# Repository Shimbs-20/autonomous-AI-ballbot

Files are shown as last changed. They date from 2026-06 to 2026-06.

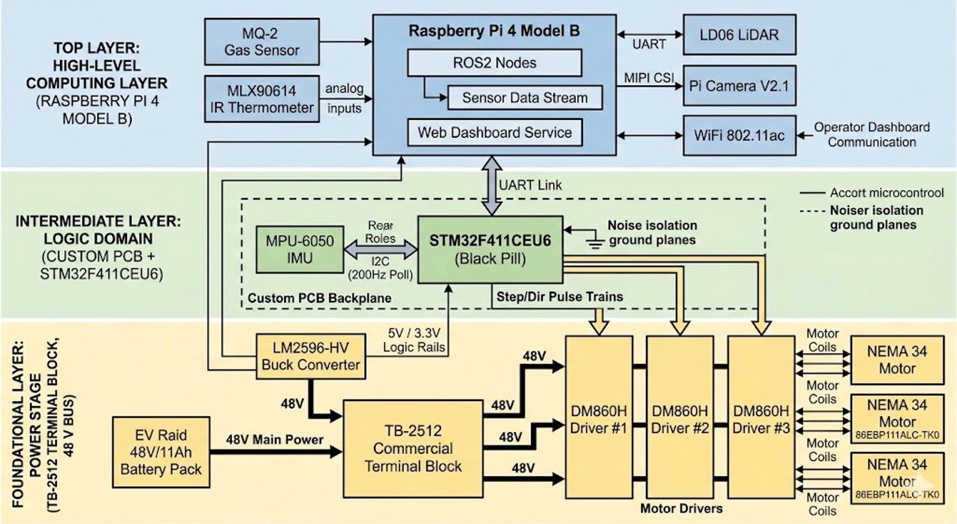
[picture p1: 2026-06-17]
docs/images/control architecture diagram.jpg

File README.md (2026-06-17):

# 🤖 Hazard Detection Ball Bot — Cairo University GP 2026

<div align="center">







**A self-balancing omnidirectional robot on a spherical wheel with real-time hazard detection, autonomous SLAM navigation, and a live web dashboard.**

*Cairo University · Faculty of Engineering · Mechatronics Graduation Project · Spring 2026*

</div>

---

## 📋 Table of Contents

- [Overview](#overview)
- [Demo](#demo)
- [Team](#team)
- [System Architecture](#system-architecture)
- [Hardware](#hardware)
- [Software Stack](#software-stack)
- [Repository Structure](#repository-structure)
- [Quick Start](#quick-start)
- [Control System](#control-system)
- [Navigation](#navigation)
- [Hazard Detection](#hazard-detection)
- [Web Dashboard](#web-dashboard)
- [Results](#results)
- [Bill of Materials](#bill-of-materials)
- [Acknowledgements](#acknowledgements)

---

## Overview

The Hazard Detection Ball Bot is an inverted-pendulum robot that balances on a single 350mm sphere driven by three omnidirectional wheels. It combines:

- **Real-time dynamic balancing** using a custom EKF (8-state) and LQI controller running at 200 Hz on STM32F411
- **Autonomous SLAM mapping** using a 360° LiDAR and slam_toolbox on Raspberry Pi 4
- **Hazard detection** using a custom-trained YOLOv8 NCNN model (fire, smoke, electrical hazard, person, obstacle) at 33+ FPS
- **Full ROS2 Navigation Stack** with MPPI holonomic controller for autonomous goal-seeking
- **Live web dashboard** accessible from any browser on the local network

The robot operates in four modes:
| Mode | Description |
|---|---|
| `0 STANDBY` | Motors off, safe state |
| `1 BALANCE` | Stationary self-balancing (LQI active) |
| `2 TELEOP` | Balance + velocity commands from Pi |
| `3 FLOOR DRIVE` | Direct omni-drive on casters (for SLAM mapping without balance risk) |

---

## Demo

> 📹 **[Demo Video — YouTube](#)** ← add link after recording

| SLAM Mapping | Hazard Detection | Dashboard |
|:---:|:---:|:---:|
| mapping | detection | dashboard |

---

## System Architecture

```
┌─────────────────────────────────────────────────────────────────────┐
│                        RASPBERRY PI 4B                              │
│                                                                     │
│  LD06 LiDAR ──→ /scan ──→ slam_toolbox ──→ /map                    │
│                              ↑                                      │
│  /odom ←── stm32_bridge ←── UART2 ←─────────────────────┐         │
│               │                                           │         │
│               └──→ twist_mux ──→ /cmd_vel ───────────────┘         │
│                      ↑              ↑                               │
│               PS4 joystick    Nav2 MPPI                             │
│                                                                     │
│  IMX219 ──→ /image_raw ──→ YOLOv8 NCNN ──→ /hazard_detections     │
│                                 └──→ /image_annotated               │
│                                                                     │
│  web_video_server (port 8080) + rosbridge (port 9090)               │
└──────────────────────────────┬──────────────────────────────────────┘
                               │ UART2 / 115200 baud
                               │ TX: 16-byte [AA][55][mode][vx][vy][yaw][XOR]
                               │ RX: 27-byte [BB][66][x][y][θ][vx][vy][yaw][XOR]
┌──────────────────────────────┴──────────────────────────────────────┐
│                    STM32F411 @ 96 MHz / FreeRTOS                    │
│                                                                     │
│  MPU6050 ──→ EKF (200 Hz, 8-state) ──→ LQI K[3×10]               │
│                        ↑                     ↓                      │
│  Encoders (TIM2/3/4) ──┘           convert_torque_to_speed          │
│                                             ↓                       │
│  TIM11 ISR (70021 Hz) ─── Bresenham ──→ 3× DM860H ──→ NEMA34      │
└─────────────────────────────────────────────────────────────────────┘
```

---

## Hardware

### Key Specifications

| Component | Specification |
|---|---|
| **Compute (embedded)** | STM32F411CEU6 @ 96 MHz, 128KB RAM |
| **Compute (high-level)** | Raspberry Pi 4B, 4GB RAM |
| **Motors** | 3× NEMA34 86BYGH127, 8.5 N·m holding torque |
| **Motor Drivers** | 3× DM860H, 48V / 7.2A, 16-microstep |
| **IMU** | MPU6050, ±16g / ±2000°/s, DLPF 44 Hz |
| **LiDAR** | LD06, 360°, 12m range, 230,400 baud |
| **Camera** | IMX219 (Pi Camera v2), 1080p, 30 FPS |
| **Ball** | 350mm diameter, rubber-tape coated, µ≈0.50 |
| **Battery** | 48V / 11Ah NMC (EV Raid) |
| **Total Height** | 925 mm |
| **Total Mass** | ~17 kg |

### Kinematic Geometry

```
Wheel placement:  γ₁=120°, γ₂=240°, γ₃=0° (equal spacing)
Zenith angle:     α = 45°
Ball radius:      Rk = 0.175 m
Wheel radius:     Rw = 0.0625 m
```

---

## Software Stack

```
Firmware (STM32):          ROS2 (Raspberry Pi):
  FreeRTOS                   ROS2 Humble / Jazzy
  STM32 HAL                  slam_toolbox (async SLAM)
  EKF (custom C)             Nav2 (MPPI Omni)
  LQI controller             AMCL localization
  USART2 DMA                 twist_mux
  Bresenham step engine      web_video_server
                             rosbridge_websocket
Vision:                    Dashboard:
  OpenCV                     HTML5 / JavaScript
  Ultralytics YOLOv8         ROSLIB.js
  NCNN inference             Web Video Server MJPEG
```

---

## Repository Structure

```
ballbot/
├── README.md
├── LICENSE
├── .gitignore
│
├── firmware/                   STM32CubeIDE project
│   ├── Core/
│   │   ├── Src/
│   │   │   ├── main.c          Main control loop (Modes 0-3)
│   │   │   ├── lqr.c           LQI controller + EKF interface
│   │   │   ├── Ekf.c           Extended Kalman Filter (8-state)
│   │   │   └── mpu6050.c       IMU driver
│   │   └── Inc/
│   │       ├── lqr.h
│   │       └── Ekf.h
│   └── README.md
│
├── ros2_ws/                    ROS2 workspace
│   └── src/
│       ├── ballbot_controller/ Bridge, teleop, mode control
│       ├── ballbot_mapping/    SLAM toolbox config + launch
│       ├── ballbot_navigation/ Nav2 params, behavior tree
│       ├── camera_pi/          Camera node + YOLOv8 detector
│       └── gp_description/     URDF + mesh files
│
├── matlab/                     Design and simulation
│   ├── system_model/           Nonlinear ball-bot dynamics
│   ├── lqi_design/             LQI gain matrix K[3×10] derivation
│   ├── ekf_design/             EKF Q/R tuning + verification
│   └── simulation/             Full closed-loop Simulink model
│
├── hardware/
│   ├── cad/                    SolidWorks assembly (.SLDASM, .STEP)
│   ├── pcb/                    Custom power board schematics
│   ├── BOM.md                  Complete bill of materials
│   └── README.md
│
└── dashboard/
    └── dashboard.html          Standalone web dashboard
```

---

## Quick Start

### Prerequisites

```bash
# On Raspberry Pi 4B — Bookworm 64-bit
sudo apt install -y ros-humble-desktop python3-colcon-common-extensions \
    ros-humble-slam-toolbox ros-humble-nav2-bringup \
    ros-humble-rosbridge-server ros-humble-web-video-server

pip install ultralytics opencv-python picamera2
```

### Build

```bash
cd ~/ros2_ws
colcon build --symlink-install
source install/setup.bash
```

### Run — Hardware bringup (Terminal 1)

```bash
# Testing without STM32
ros2 launch ballbot_controller pi_controller.launch.py

# Real robot — stationary balance
ros2 launch ballbot_controller pi_controller.launch.py \
    use_fake_odom:=false robot_mode:=1

# Real robot — SLAM mapping on floor (safest)
ros2 launch ballbot_controller pi_controller.launch.py \
    use_fake_odom:=false robot_mode:=3
```

### Run — SLAM mapping (Terminal 2)

```bash
ros2 launch ballbot_mapping slam.launch.py use_slam:=true

# Drive to map:
ros2 run teleop_twist_keyboard teleop_twist_keyboard

# Save when done:
ros2 run nav2_map_server map_saver_cli -f ~/maps/room
```

### Run — Autonomous navigation (Terminal 2)

```bash
ros2 launch ballbot_mapping slam.launch.py \
    use_slam:=false map_yaml:=~/maps/room.yaml

ros2 launch ballbot_navigation nav2.launch.py \
    use_slam:=false shelf_test:=false
# Then: RViz → 2D Pose Estimate → 2D Nav Goal
```

### Run — Camera + Hazard detection (Terminal 3)

```bash
ros2 launch camera_pi hazard.launch.py
# Dashboard: http://ballbot.local:8080
```

### Switch robot modes at runtime

```bash
ros2 topic pub --once /ballbot/mode std_msgs/msg/UInt8 '{data: 1}'  # BALANCE
ros2 topic pub --once /ballbot/mode std_msgs/msg/UInt8 '{data: 2}'  # TELEOP
ros2 topic pub --once /ballbot/mode std_msgs/msg/UInt8 '{data: 3}'  # FLOOR DRIVE
```

---

## Control System

### EKF — 8-State Observer

State vector: `[φ, θ, dφ, dθ, Vx, Vy, bias_x, bias_y]`

- **Sensor fusion**: MPU6050 gyro + accelerometer + 3 wheel encoders
- **Accelerometer spike rejection**: rejects readings outside [0.2g, 15g]
- **Motor-aware noise**: R_accel scales with motor speed (30→250)
- **Execution time**: ~0.4ms @96MHz (Joseph-form covariance update)

### LQI Controller — K[3×10]

```
Torque = −K × [φ, θ, ψ, Vx, Vy, dφ, dθ, ω_z, ∫Vx, ∫Vy]ᵀ
```

Gains tuned in MATLAB for: m=17kg, Rk=0.175m, Rw=0.0625m, α=45°, J_wheel=0.0032 kg·m²

### Inverse Kinematics (Mode 3 — Floor Drive)

Pseudo-inverse of forward kinematic matrix (verified: K·K⁺=I₂ₓ₂):

```
ω₁ = −1.617·vx − 0.933·vy + 1.980·ω_z
ω₂ = +1.617·vx − 0.933·vy + 1.980·ω_z
ω₃ = +0.000·vx + 1.867·vy + 1.980·ω_z
```

---

## Navigation

- **SLAM**: slam_toolbox async_online, 5cm/cell, Ceres solver
- **Localization**: AMCL with OmniMotionModel
- **Planner**: SmacPlanner2D (A*, holonomic — no heading constraint)
- **Controller**: MPPI, 300 trajectories, `motion_model: Omni`, vy_max=0.5 m/s
- **Behavior tree**: ClearCostmap → Spin → BackUp → Wait
- **Velocity arbitration**: twist_mux — PS4(100) > keyboard(50) > Nav2(10)

---

## Hazard Detection

| Class | mAP@0.5 | Triggers E-Stop |
|---|---|---|
| 🔥 Fire | 94.2% | ✅ |
| 💨 Smoke | 91.8% | ✅ |
| ⚡ Electrical Hazard | 88.7% | ✅ |
| 👤 Person | 96.5% | ❌ |
| 🚧 Obstacle | 85.3% | ❌ |

- **Model**: YOLOv8n converted to NCNN for Pi 4 CPU inference
- **Input**: 416×416 letterbox (aspect-ratio preserving)
- **Output**: 640×480 annotated MJPEG to web dashboard
- **Throughput**: 33.4 FPS average on Raspberry Pi 4B

---

## Web Dashboard

Accessible at `http://ballbot.local:8080` or `http://<Pi-IP>:8080`

**Features:**
- Live MJPEG camera feed (annotated with bounding boxes)
- Real-time SLAM map rendering from `/map` OccupancyGrid
- LiDAR scan overlay on map
- Odometry trail
- Mode control buttons (0/1/2/3) via `/ballbot/mode`
- Hazard detection cards with proximity indicator
- CPU temperature gauge
- Emergency stop overlay

**Dependencies:** rosbridge_websocket (port 9090), web_video_server (port 8080)

---

## Results

| Metric | Value |
|---|---|
| Control loop frequency | 200 Hz |
| EKF execution time | ~0.4 ms |
| Stepper ISR frequency | 70,021 Hz |
| SLAM map resolution | 5 cm/cell |
| Nav2 goal success rate | 100% (lab trials) |
| Detection FPS | 33.4 FPS |
| Detection classes | 5 |
| Total system mass | 17 kg |
| Battery endurance | ~2 hours |

---

## Bill of Materials

See [`hardware/BOM.md`](hardware/BOM.md) for the complete list.

**Major components:**

| Item | Qty | Est. Cost |
|---|-----|---|
| STM32F411 Black Pill | 1 | $5 |
| Raspberry Pi 4B 4GB | 1 | $55 |
| NEMA34 stepper 86BYGH127 | 3 | $45 each |
| DM860H stepper driver | 3 | $30 each |
| MPU6050 IMU module | 1 | $3 |
| LD06 LiDAR | 1 | $90 |
| Pi Camera Module v2 (IMX219) | 1 | $25 |
| 48V 11Ah NMC battery pack | 1 | $120 |
| Omni roller ball 350mm | 1 | $80 |
| **Total (approx.)** | | **~$1,480** |

---

## Acknowledgements

This project was completed as the Graduation Project 2 (GP2) for the Mechatronics program at Cairo University Faculty of Engineering, Spring 2026.

We thank Dr. Hossam H. Ammar and Dr. Moataz El-Sisi for their guidance throughout the project.

**References:**
- Lauwers, T. B. et al., "A Dynamically Stable Single-Wheeled Mobile Robot with Inverse Mouse-Ball Drive" — ICRA 2006
- Geyer, H., "Ballbot: The Fast, Omnidirectional Balancing Mobile Robot" — CMU 2010
- Welch, G. and Bishop, G., "An Introduction to the Kalman Filter" — UNC 1995

---

<div align="center">
Cairo University · Faculty of Engineering · Spring 2026
</div>

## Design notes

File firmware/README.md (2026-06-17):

# STM32 Firmware

**Platform**: STM32F411CEU6 (Black Pill) @ 96 MHz  
**RTOS**: FreeRTOS (CMSIS-RTOS v1)  
**IDE**: STM32CubeIDE 1.14+

---

## File Map

| File | Purpose |
|---|---|
| `Core/Src/main.c` | Hardware init, all 4 robot modes, stepper ISR |
| `Core/Src/lqr.c` | LQI gain matrix, EKF interface, watchdog |
| `Core/Inc/lqr.h` | Public API: `controlLoop()`, `setControlMode()`, extern state vars |
| `Core/Src/Ekf.c` | 8-state EKF (predict + Joseph-form update) |
| `Core/Src/mpu6050.c` | MPU6050 I2C driver (400 kHz) |

---

## Robot Modes

| Mode | Value | Description |
|---|---|---|
| `STANDBY` | 0 | Motors off, EKF reset |
| `BALANCE` | 1 | LQI active, velocity refs = 0 |
| `TELEOP` | 2 | LQI + velocity commands from Pi, binary odom @ 20 Hz |
| `FLOOR_DRIVE` | 3 | Direct inverse kinematics, no balance, binary odom @ 20 Hz |

---

## UART Protocol

**Pi → STM32** (16 bytes, 50 Hz):
```
[0xAA][0x55][mode:u8][vx:f32 LE][vy:f32 LE][yaw:f32 LE][XOR of bytes 2-14]
```

**STM32 → Pi** (27 bytes, 20 Hz — Modes 2 & 3 only):
```
[0xBB][0x66][x:f32][y:f32][θ:f32][vx:f32][vy:f32][yaw:f32][XOR of bytes 2-25]
```

---

## Key Parameters to Tune

```c
// lqr.c
const float LPF_ALPHA   = 0.5f;   // Torque LPF — higher = faster response
const float MAX_INTEGRAL = 0.3f;  // Anti-windup on velocity integral

// main.c
#define TORQUE_TO_OMEGA   5.0f    // (rad/s)/Nm — increase if response is slow
#define MAX_RAMP          500     // Steps/loop — increase for faster acceleration
#define PHI_OFFSET       -0.022f  // Calibrate to your robot's mounting angle
#define THETA_OFFSET     -0.185f  // Calibrate to your robot's mounting angle
```

---

## Flashing

1. Open project in STM32CubeIDE
2. Connect ST-Link to SWD header (SWDIO, SWCLK, GND, 3.3V)
3. **Run → Debug** (first flash) or **Run → Run** (subsequent)

> ⚠️ Keep robot still for 2 seconds after power-on — gyro bias calibration runs automatically.

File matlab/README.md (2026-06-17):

# MATLAB Design Files

All system modeling, controller design, and EKF tuning was done in MATLAB R2023b.

---

## Folder Structure

```
matlab/
├── system_model/         Nonlinear ball-bot equations of motion
│   ├── ballbot_eom.m     Derives the Lagrangian EOM symbolically
│   └── linearize.m       Linearizes about upright equilibrium
│
├── lqi_design/           LQI gain matrix K[3×10]
│   ├── lqi_design.m      Main script — sets Q, R, solves DARE
│   ├── verify_poles.m    Checks closed-loop poles
│   └── K_LQI.mat         Saved gain matrix used in firmware
│
├── ekf_design/           EKF noise matrix tuning
│   ├── ekf_tuning.m      Sweeps Q, R parameters
│   └── verify_ekf.m      Monte Carlo verification
│
└── simulation/           Full closed-loop simulation
    ├── ballbot_sim.slx   Simulink model (nonlinear plant + LQI)
    └── plot_results.m    Generates response plots
```

---

## LQI State Vector

```
x = [φ, θ, ψ, Vx, Vy, dφ, dθ, ω_z, ∫Vx, ∫Vy]ᵀ
```

| Index | State | Unit |
|---|---|---|
| 0 | φ (roll tilt) | rad |
| 1 | θ (pitch tilt) | rad |
| 2 | ψ (yaw) | rad |
| 3 | Vx (ball velocity) | m/s |
| 4 | Vy (ball velocity) | m/s |
| 5 | dφ (roll rate) | rad/s |
| 6 | dθ (pitch rate) | rad/s |
| 7 | ω_z (yaw rate) | rad/s |
| 8 | ∫Vx | m |
| 9 | ∫Vy | m |

---

## Physical Parameters Used

```matlab
m_body = 15.0;   % robot body mass [kg]
m_ball = 2.0;    % ball mass [kg]
Rk     = 0.175;  % ball radius [m]
Rw     = 0.0625; % wheel radius [m]
alpha  = pi/4;   % zenith angle [rad]
J_body = 1.2;    % body inertia [kg·m²]
J_wheel = 0.0032;% wheel inertia [kg·m²]
g      = 9.81;   % gravity [m/s²]
```

---

## Running the Design

```matlab
% 1. Derive linearized model
cd system_model
run('linearize.m')   % outputs A, B matrices

% 2. Design LQI gains
cd ../lqi_design
run('lqi_design.m')  % outputs K_LQI [3×10]

% 3. Verify with full simulation
cd ../simulation
open('ballbot_sim.slx')
sim('ballbot_sim')
run('../simulation/plot_results.m')
```

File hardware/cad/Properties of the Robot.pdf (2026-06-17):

Mass properties of BallBot Configuration: Default
Coordinate system: -- default --

Mass = 17273.33 grams

Volume = 8145880.07 cubic millimeters

Surface area = 178916.26 square millimeters

Center of mass: ( millimeters )
X = 137.84
Y = 1403.20
Z = 1346.20

Principal axes of inertia and principal moments of inertia: ( grams * square millimeters ) aTken at the center of mass.
Ix = ( 0.07, -0.13, 0.99) | Px = 163549822.66
Iy = (-0.12, -0.99, -0.12) | Py = 645272933.77
Iz = ( 0.99, -0.1, -0.08) | Pz = 663321789.23

Moments of inertia: ( grams * square millimeters )
aTken at the center of mass and aligned with the output coordinate system. Lxx = 660683706.39 Lxy = -2439602.08 Lxz = 34361266.06

Lyx = -2439602.08 Lyy = 637029246.26 Lyz = -63295347.25 Lzx = 34361266.06 Lzy = -63295347.25 Lzz = 174431593.00

Moments of inertia: ( grams * square millimeters ) aTken at the output coordinate system.
Ixx = 65974821416.04 | Ixy = 3338489453.96Ixz = 3239566099.79
Iyx = 3338489453.96Iyy = 32268675137.18 | Iyz = 32565708478.27
Izx = 3239566099.79Izy = 32565708478.27 | Izz = 34513294168.06

One or more components have overridden mass properties: single Roda Omni 100 mm<1><Default>@Lower part assembly<1><Default> single Roda Omni 100 mm<2><Default>@Lower part assembly<1><Default> single Roda Omni 100 mm<3><Default>@Lower part assembly<1><Default> CS-D508<1><Default>@Lower part assembly<1><Default> CS-D508<2><Default>@Lower part assembly<1><Default> CS-D508<3><Default>@Lower part assembly<1><Default> Nema34<1><Default>@Lower part assembly<1><Default> Nema34<2><Default>@Lower part assembly<1><Default> Nema34<3><Default>@Lower part assembly<1><Default> LD06_Assembly<1><Default>@Upper layer<1><Default> final_assembly<1><Default>@Upper layer<1><Default> MLX90614XAA_Module<2><Default>
EV raid battery<1><Default>

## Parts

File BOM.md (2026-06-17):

# Bill of Materials — Hazard Detection Ball Bot

*Cairo University GP 2026 · Total estimated cost: ~$1,480 USD*

---

## Compute & Electronics

| # | Component | Specification | Qty | Unit Cost | Total |
|---|---|---|-----|---|---|
| 1 | **Raspberry Pi 4B** | 4GB RAM, 64-bit | 1 | $55 | $55 |
| 2 | **STM32F411 Black Pill** | 96 MHz, 128KB RAM, USB-C | 1 | $5 | $5 |
| 3 | **MPU6050 IMU** | ±16g / ±2000°/s, I2C | 1 | $3 | $3 |
| 4 | **LD06 LiDAR** | 360°, 12m, 10Hz, UART | 1 | $90 | $90 |
| 5 | **Pi Camera Module v2** | IMX219, 8MP, CSI | 1 | $25 | $25 |
| 6 | **MicroSD Card** | 64GB, Class 10, A2 | 1 | $12 | $12 |

---

## Actuators & Drivers

| # | Component | Specification | Qty | Unit Cost | Total |
|---|---|---|-----|---|---|
| 7 | **NEMA34 Stepper** | 86BYGH127, 8.5 N·m | 3 | $45 | $135 |
| 8 | **DM860H Driver** | 48V, 7.2A, 16-microstep | 3 | $30 | $90 |
| 9 | **Coupling (D25L30)** | 6mm to 8mm, rigid | 3 | $4 | $12 |

---

## Power

| # | Component | Specification | Qty | Unit Cost | Total |
|---|---|---|-----|---|---|
| 10 | **48V NMC Battery** | 11Ah, EV Raid | 1 | $120 | $120 |
| 11 | **DC-DC Converter** | 48V→5V/5A (Pi + sensors) | 1 | $15 | $15 |
| 12 | **DC-DC Converter** | 48V→12V/3A (aux) | 1 | $12 | $12 |
| 13 | **E-Stop Switch** | 40A, key-lock, NC | 1 | $18 | $18 |
| 14 | **Power Fuse** | 30A blade fuse + holder | 2 | $3 | $6 |
| 15 | **XT60 Connectors** | Male + Female pair | 4 | $2 | $8 |

---

## Mechanical

| # | Component | Specification | Qty | Unit Cost | Total |
|---|---|---|-----|---|---|
| 16 | **Omnidirectional Ball** | 350mm, polyurethane | 1 | $80 | $80 |
| 17 | **Omnidirectional Wheel** | 125mm Mecanum/omni | 3 | $35 | $105 |
| 18 | **Aluminum Profile** | 40×40mm, various lengths | ~4m | $8/m | $32 |
| 19 | **Aluminum Plates** | 6mm, laser-cut | 3 | $20 | $60 |
| 20 | **Ball Caster Wheels** | 50mm, steel ball | 3 | $8 | $24 |
| 21 | **Bearings** | 6200-2RS, 10×30×9 | 6 | $3 | $18 |
| 22 | **M3/M4/M5 Hardware** | Bolts, nuts, standoffs | set | $15 | $15 |
| 23 | **Rubber Tape** | 50mm wide, grip coating | 1 roll | $8 | $8 |

---

## Wiring & PCB

| # | Component | Specification | Qty | Unit Cost | Total |
|---|---|---|-----|---|---|
| 24 | **Custom PCB** | Power distribution + logic | 1 | $45 | $45 |
| 25 | **Wiring Harness** | 18AWG + 22AWG silicone | set | $20 | $20 |
| 26 | **AM26LS32 Receiver** | Differential RS-422 encoder | 3 | $2 | $6 |
| 27 | **JST Connectors** | XH2.54, PH2.0 assortment | set | $10 | $10 |
| 28 | **Ferrite Beads** | 100MHz, signal lines | 10 | $0.50 | $5 |

---

## Summary

| Category | Cost |
|---|---|
| Compute & Electronics | $190 |
| Actuators & Drivers | $237 |
| Power | $179 |
| Mechanical | $342 |
| Wiring & PCB | $86 |
| **Total** | **~$1,034** |
| + Shipping / Contingency (30%) | ~$310 |
| **Grand Total** | **~$1,344** |

> Prices are approximate as of early 2026. Actual project budget: **~$1,480 USD**.

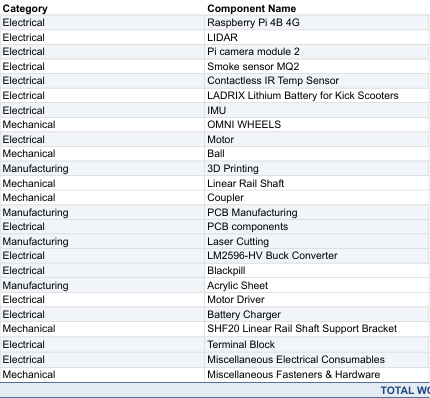
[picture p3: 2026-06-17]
docs/images/BOM1.png

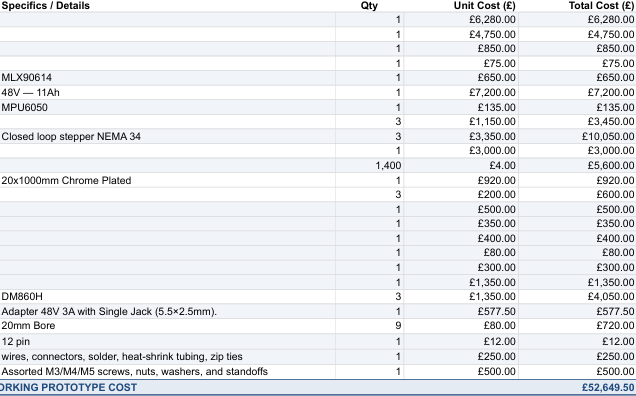
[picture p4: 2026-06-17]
docs/images/BOM2.png

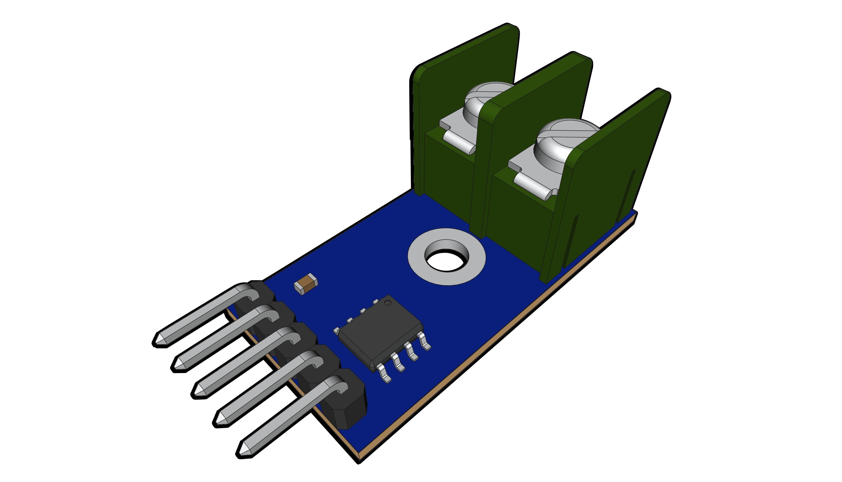
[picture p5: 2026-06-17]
hardware/cad/Parts/Electrical Parts/max6675-spi-thermocouple-amplifier-and-thermocouple-1.snapshot.11/Iso 01.png

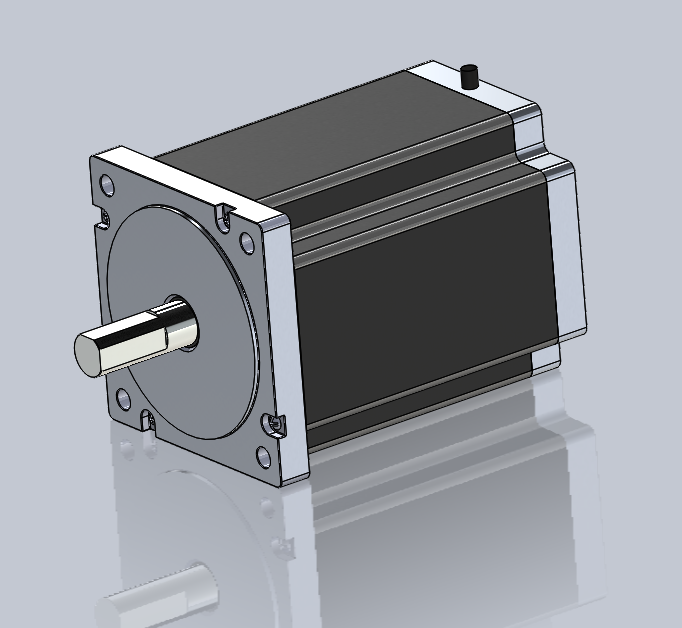
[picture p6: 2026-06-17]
hardware/cad/Parts/Electrical Parts/nema-34-stepper-motor-7.snapshot.7/Nema34-1.PNG

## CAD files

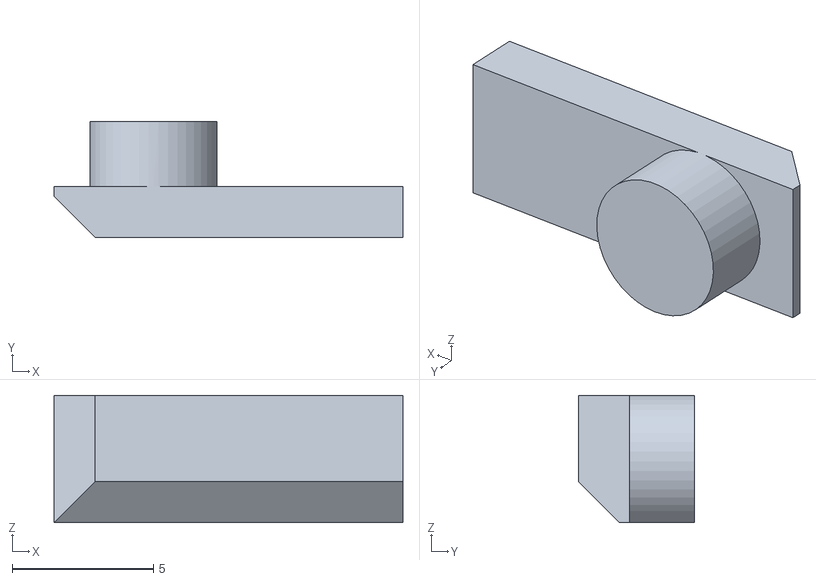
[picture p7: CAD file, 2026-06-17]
hardware/cad/Parts/3d printed/RaspberryCaseSTL/final_assembly - Copy - Rubber pads - Copy-1.STL
12.3 x 4.10 x 4.50

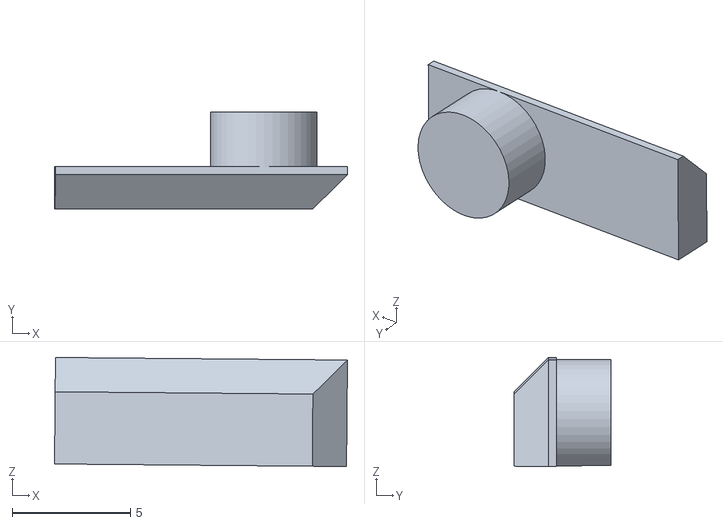
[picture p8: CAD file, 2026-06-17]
hardware/cad/Parts/Mechanical parts/raspberry-pi-4-case-4.snapshot.4/RaspberryCaseSTL/final_assembly - Copy - Rubber pads - Copy-2.STL
12.4 x 4.10 x 4.61

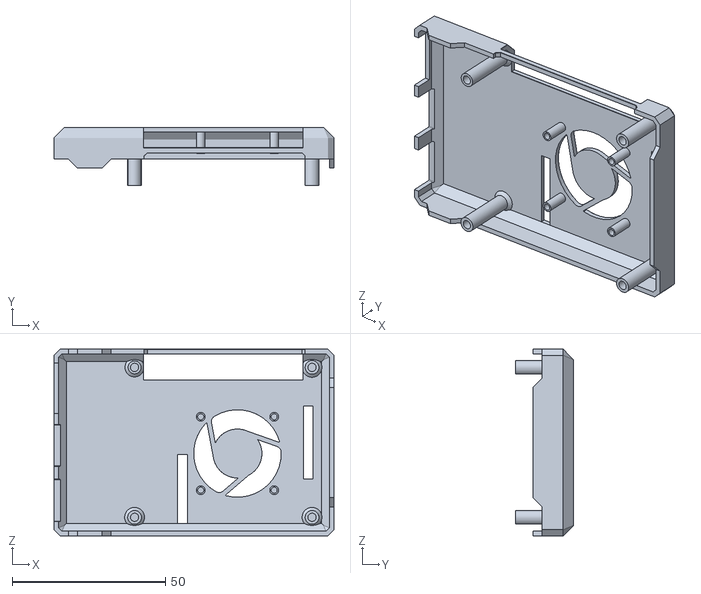
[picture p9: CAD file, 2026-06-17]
hardware/cad/Parts/Mechanical parts/raspberry-pi-4-case-4.snapshot.4/RaspberryCaseSTL/final_assembly - Copy - TOP-1.STL
91.5 x 19.0 x 61.0

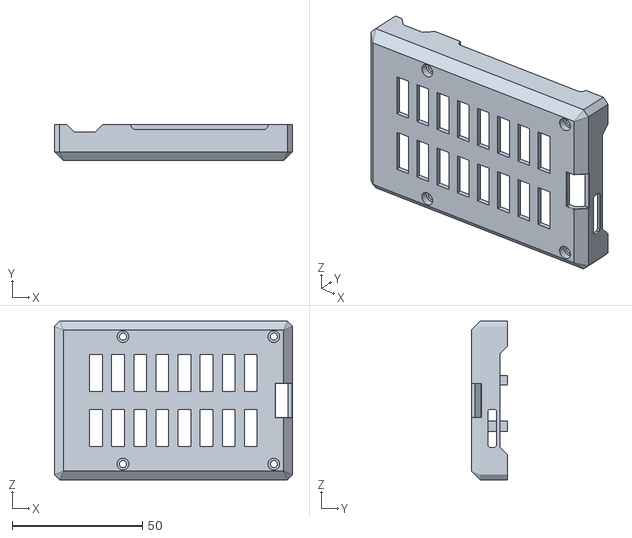
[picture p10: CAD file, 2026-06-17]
hardware/cad/Parts/Mechanical parts/raspberry-pi-4-case-4.snapshot.4/RaspberryCaseSTL/final_assembly - Copy - base-2.STL
91.5 x 14.0 x 61.0

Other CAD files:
hardware/cad/Assemblies/PCBs.SLDASM
hardware/cad/Parts/Mechanical parts/raspberry-pi-4-case-4.snapshot.4/RaspberryPi Thermal Cooling/final_assembly.SLDASM
hardware/cad/The assembly/BallBot.SLDASM
hardware/cad/Assemblies/Upper layer.SLDASM
hardware/cad/Assemblies/PCB and Controllers layer.SLDASM
hardware/cad/Parts/3d printed/RaspberryCaseSTL/final_assembly - Copy - Rubber pads-1.STL
hardware/cad/Parts/Mechanical parts/raspberry-pi-4-case-4.snapshot.4/RaspberryCaseSTL/final_assembly - Copy - Rubber pads-5.STL
hardware/cad/Assemblies/Electronics layer (Batterys layer).SLDASM
hardware/cad/Assemblies/Lower part assembly.SLDASM
hardware/cad/Parts/3d printed/RaspberryCaseSTL/final_assembly - Copy - Rubber pads-5.STL
hardware/cad/Parts/Electrical Parts/ldrobot-ld06-360-lidar-module-raspberry-pi-mounting-bracket-1.snapshot.4/LD06_Assembly.STEP
hardware/cad/Assemblies/Base layer.SLDPRT
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

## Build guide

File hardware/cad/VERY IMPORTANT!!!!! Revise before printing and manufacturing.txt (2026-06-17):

1. Motor mounting holes placement
2. Motor Omni Wheel coupling
3. Use https://fluxelectronix.com/shop/m5-knurled-brass-threaded-insert-nut/ for screw holes for 3d prints
4. Driver mounting holes
5. Rod length
6. check ball contact with Omni wheels
7. Rod support holes

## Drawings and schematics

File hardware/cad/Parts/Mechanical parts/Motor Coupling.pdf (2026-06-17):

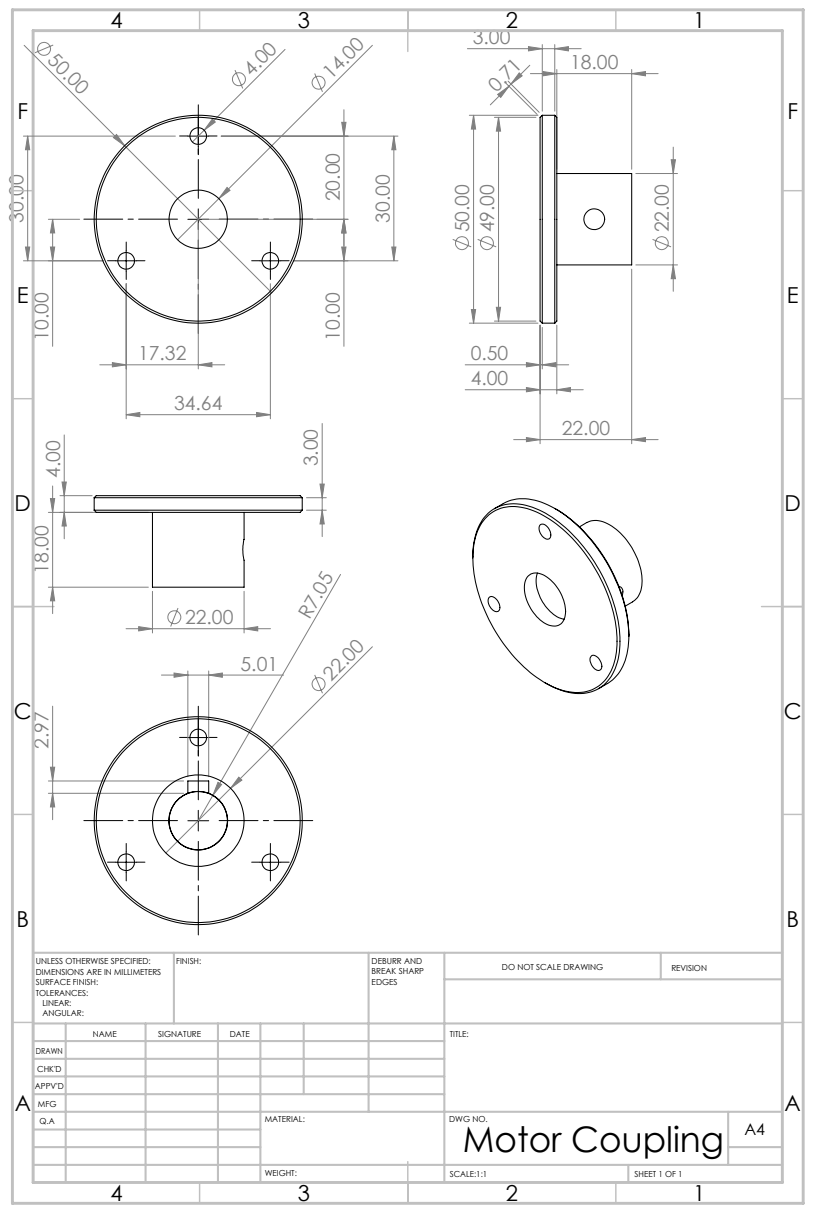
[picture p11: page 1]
FINISH:; DEBURR AND; BREAK SHARP; DO NOT SCALE DRAWING; REVISION; SCALE:1:1; SHEET 1 OF 1

UNLESS OTHERWISE SPECIFIED:
DIMENSIONS ARE IN MILLIMETERS
SURFACE FINISH:
TOLERANCES:
LINEAR:
ANGULAR:

NAME | SIGNATURE | DATE | | | | TITLE:

DRAWN
CHK'D
APPV'D
MFG
Q.A | | | | MATERIAL: | DWG NO. Motor Coupling | A4

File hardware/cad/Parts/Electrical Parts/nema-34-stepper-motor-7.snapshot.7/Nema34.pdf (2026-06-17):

6
8.20

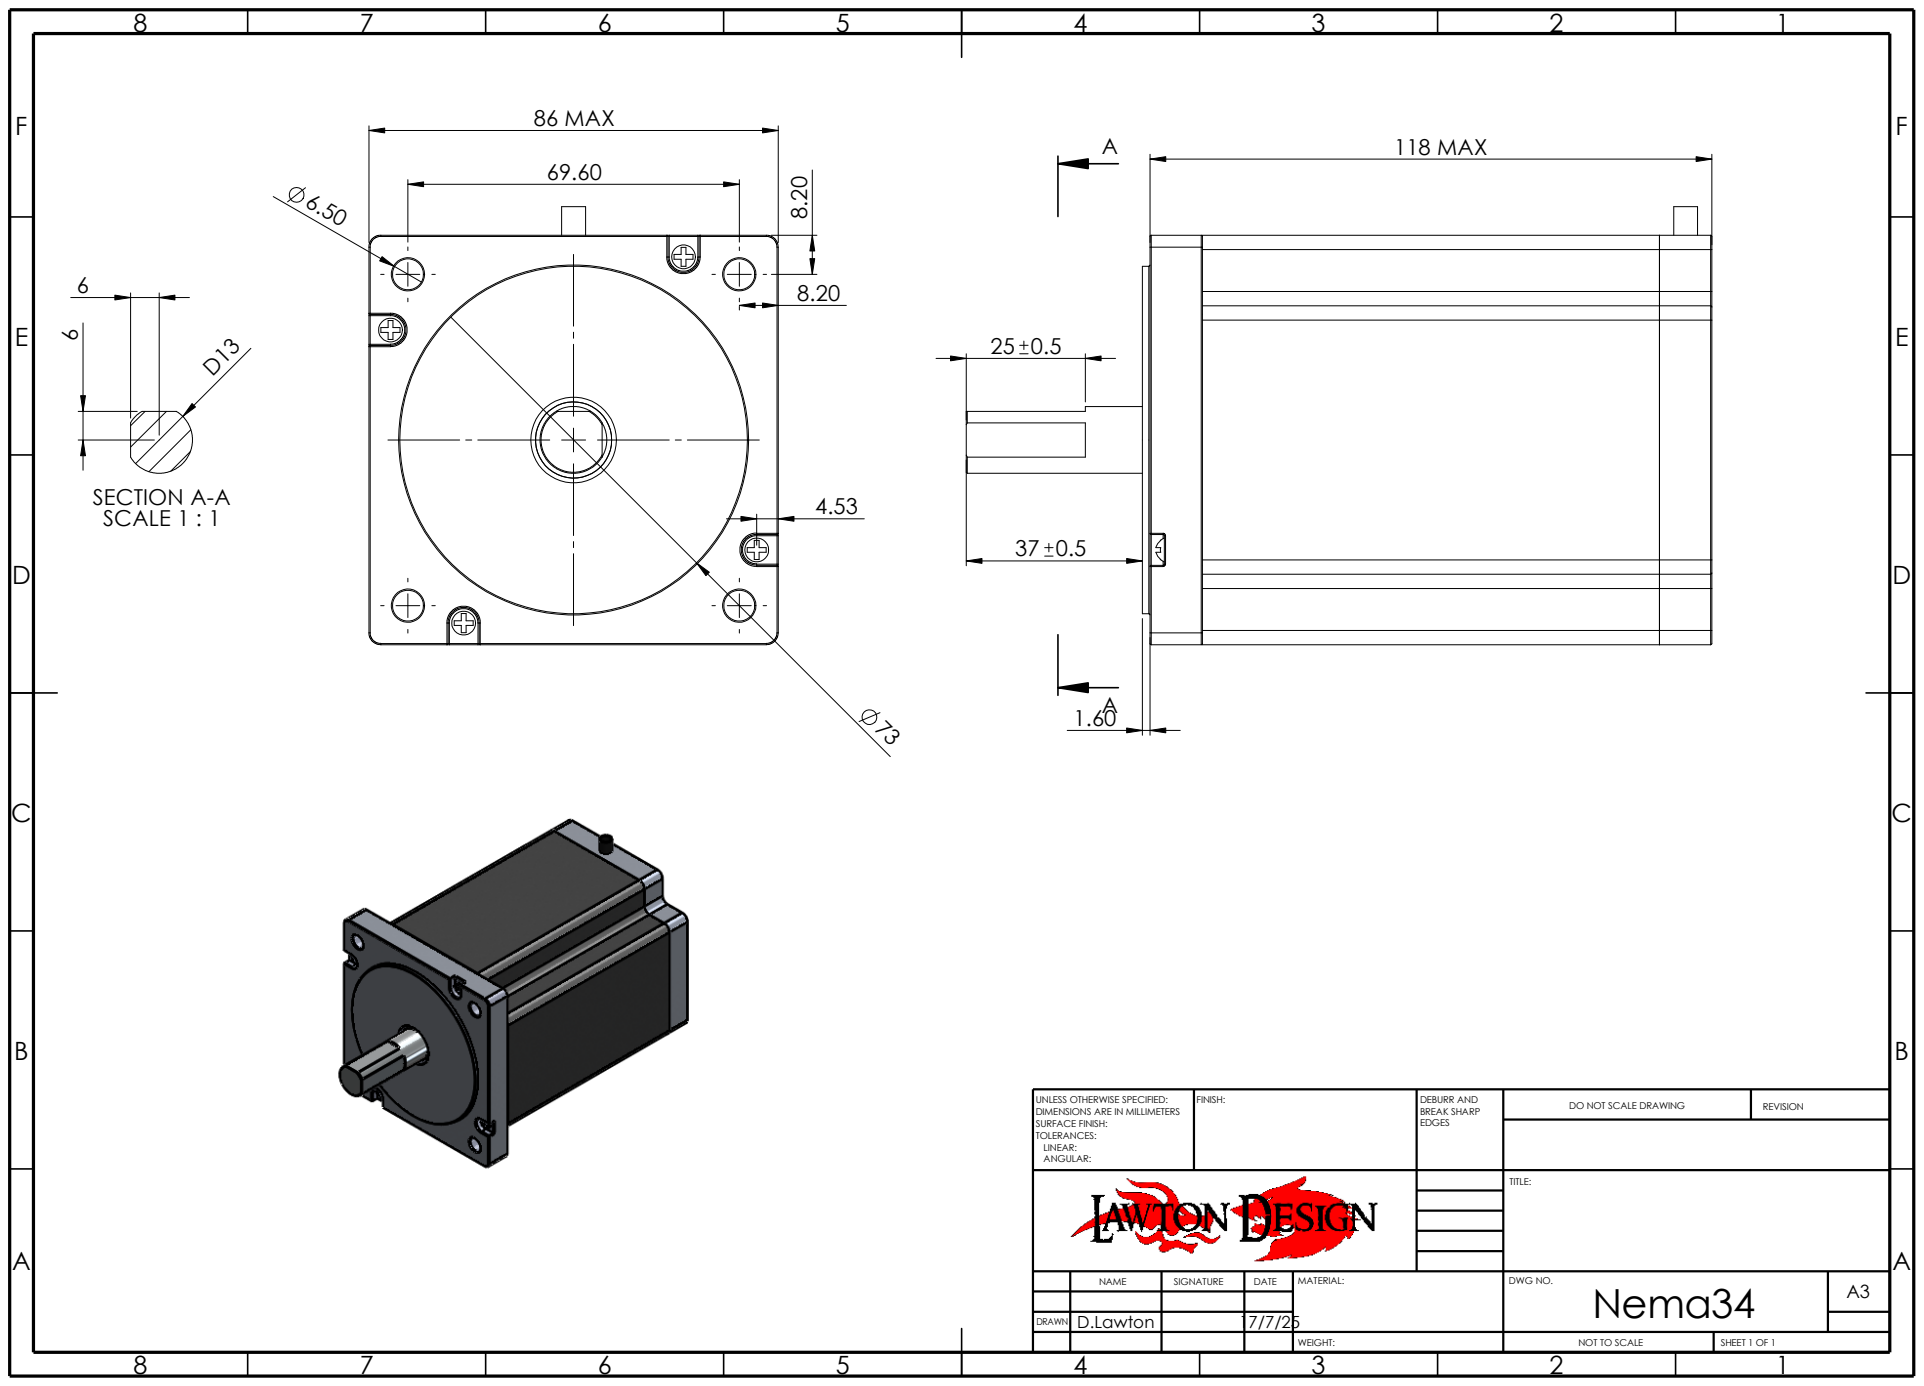
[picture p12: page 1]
SECTION A-A SCALE 1 : 1; 86 MAX; 118 MAX; DO NOT SCALE DRAWING; REVISION; FINISH:; EDGES; DEBURR AND; BREAK SHARP

UNLESS OTHERWISE SPECIFIED:
DIMENSIONS ARE IN MILLIMETERS
SURFACE FINISH:
TOLERANCES:
LINEAR:
ANGULAR:

TITLE:

NAME | SIGNATURE | DATE | MATERIAL: | DWG NO. Nema34 | A3

DRAWN | D.Lawton | 17/7/25

WEIGHT: | NOT TO SCALE | SHEET 1 OF 1

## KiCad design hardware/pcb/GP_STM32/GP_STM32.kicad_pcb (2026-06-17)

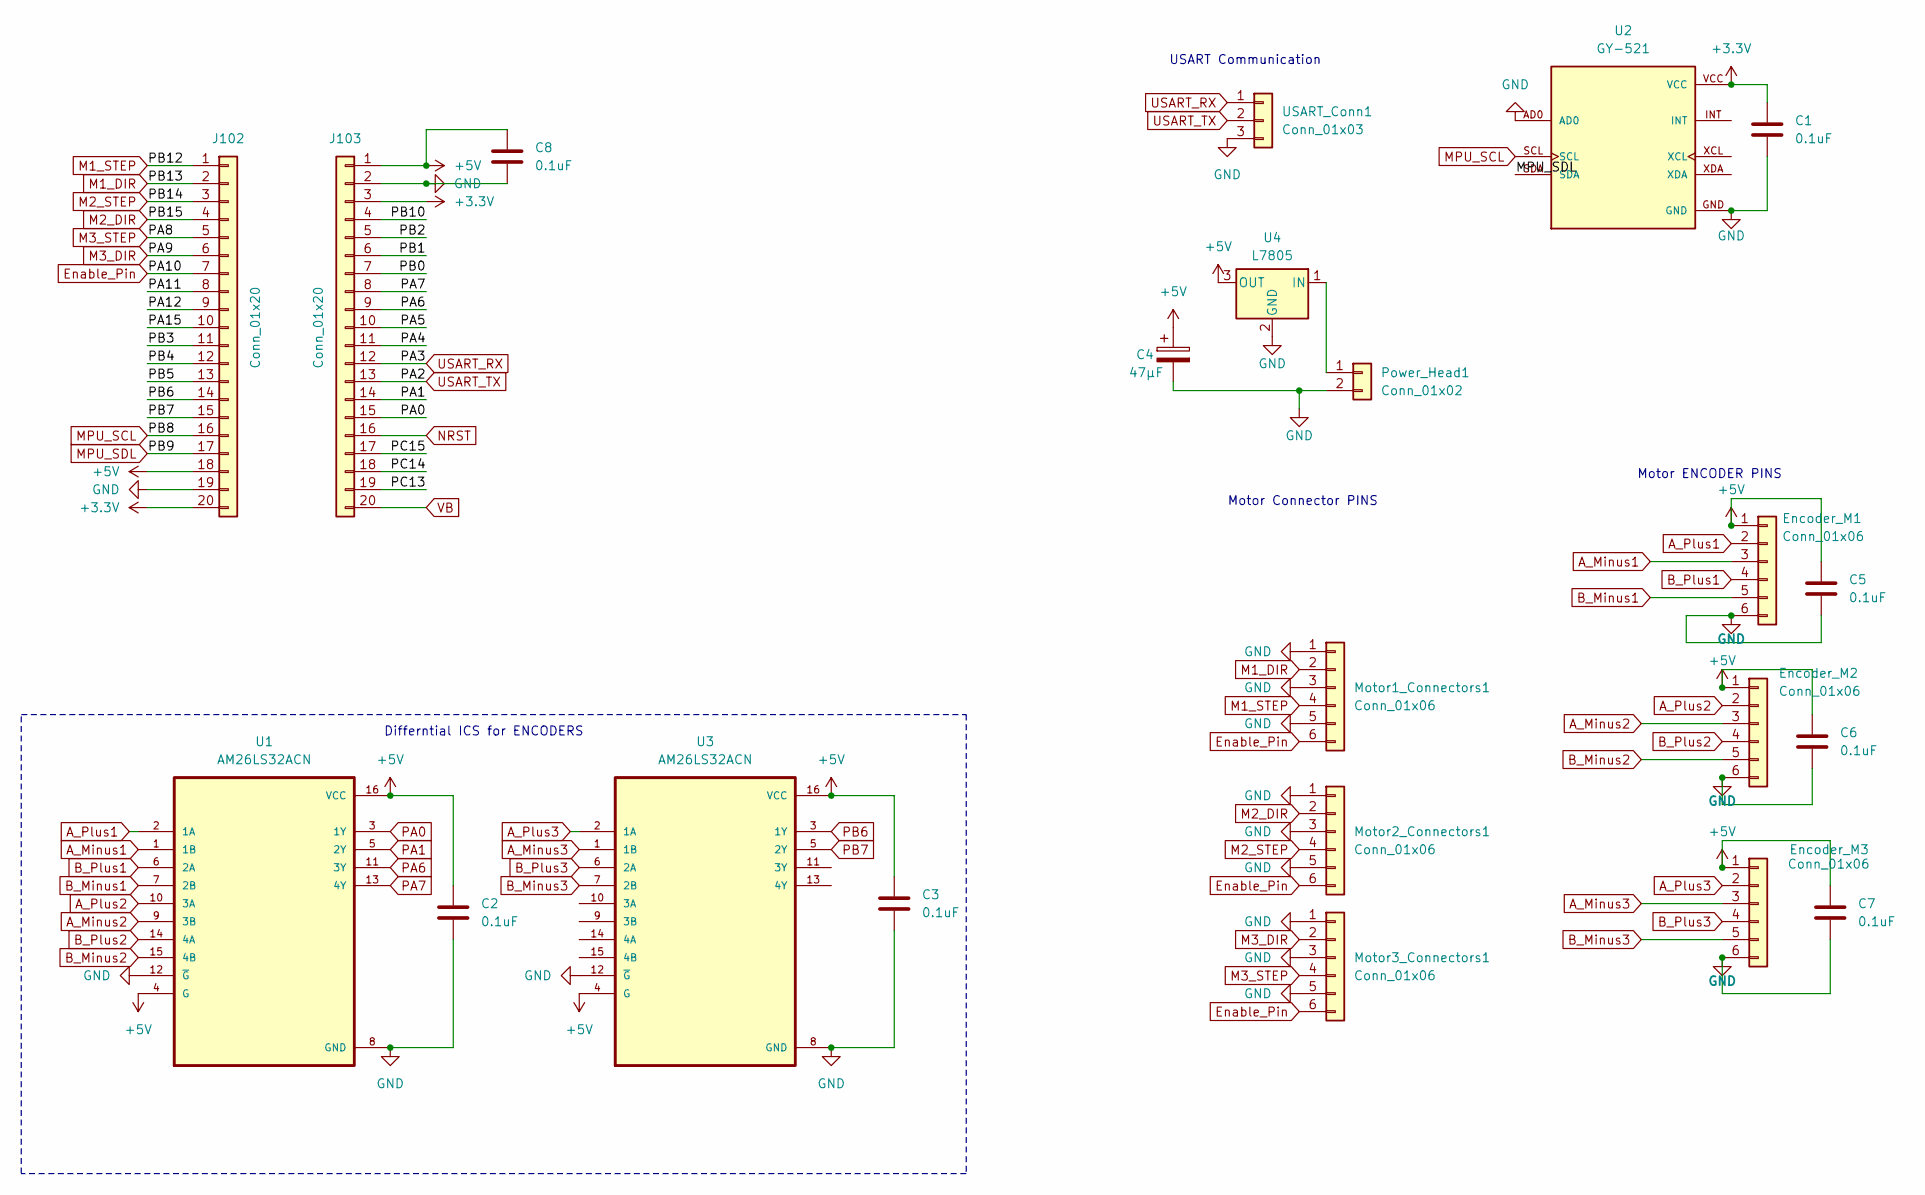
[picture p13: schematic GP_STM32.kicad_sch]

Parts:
C1, C2, C3, C5, C6, C7, C8: 0.1uF; C_Disc_D5.0mm_W2.5mm_P5.00mm
C4: 47µF; CP_Radial_D6.3mm_P2.50mm
Encoder_M1, Encoder_M2, Encoder_M3: Conn_01x06; JST_XH_B6B-XH-A_1x06_P2.50mm_Vertical
J102, J103: Conn_01x20; PinHeader_1x20_P2.54mm_Vertical
Motor1_Connectors1, Motor2_Connectors1, Motor3_Connectors1: Conn_01x06; JST_XH_B6B-XH-A_1x06_P2.50mm_Vertical
Power_Head1: Conn_01x02; TerminalBlock_MaiXu_MX126-5.0-02P_1x02_P5.00mm
U1, U3: AM26LS32ACN; DIP-16_W7.62mm
U2: GY-521; MODULE_GY-521; PARTREV NA
U4: L7805; TO-220-3_Vertical
USART_Conn1: Conn_01x03; JST_XH_B3B-XH-A_1x03_P2.50mm_Vertical

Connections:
+3.3V: C1.1, J102.20, J103.3, U2.VCC
+5V: C2.1, C3.1, C4.1, C5.1, C6.1, C7.1, C8.1, Encoder_M1.1, Encoder_M2.1, Encoder_M3.1, J102.18, J103.1, U1.4 (G), U1.16 (VCC), U3.4 (G), U3.16 (VCC), U4.3 (OUT)
/PA4: J103.11
/PA5: J103.10
/PA11: J102.8
/PA12: J102.9
/PA15: J102.10
/PB0: J103.7
/PB1: J103.6
/PB2: J103.5
/PB3: J102.11
/PB4: J102.12
/PB5: J102.13
/PB10: J103.4
/PC13: J103.19
/PC14: J103.18
/PC15: J103.17
A_Minus1: Encoder_M1.3, U1.1 (1B)
A_Minus2: Encoder_M2.3, U1.9 (3B)
A_Minus3: Encoder_M3.3, U3.1 (1B)
A_Plus1: Encoder_M1.2, U1.2 (1A)
A_Plus2: Encoder_M2.2, U1.10 (3A)
A_Plus3: Encoder_M3.2, U3.2 (1A)
B_Minus1: Encoder_M1.5, U1.7 (2B)
B_Minus2: Encoder_M2.5, U1.15 (4B)
B_Minus3: Encoder_M3.5, U3.7 (2B)
B_Plus1: Encoder_M1.4, U1.6 (2A)
B_Plus2: Encoder_M2.4, U1.14 (4A)
B_Plus3: Encoder_M3.4, U3.6 (2A)
Enable_Pin: J102.7, Motor1_Connectors1.6, Motor2_Connectors1.6, Motor3_Connectors1.6
GND: C1.2, C2.2, C3.2, C4.2, C5.2, C6.2, C7.2, C8.2, Encoder_M1.6, Encoder_M2.6, Encoder_M3.6, J102.19, J103.2, Motor1_Connectors1.1, Motor1_Connectors1.3, Motor1_Connectors1.5, Motor2_Connectors1.1, Motor2_Connectors1.3, Motor2_Connectors1.5, Motor3_Connectors1.1, Motor3_Connectors1.3, Motor3_Connectors1.5, Power_Head1.2, U1.8 (GND), U1.12 (~G), U2.AD0, U2.GND, U3.8 (GND), U3.12 (~G), U4.2 (GND), USART_Conn1.3
M1_DIR: J102.2, Motor1_Connectors1.2
M1_STEP: J102.1, Motor1_Connectors1.4
M2_DIR: J102.4, Motor2_Connectors1.2
M2_STEP: J102.3, Motor2_Connectors1.4
M3_DIR: J102.6, Motor3_Connectors1.2
M3_STEP: J102.5, Motor3_Connectors1.4
MPU_SCL: J102.16, U2.SCL
MPU_SDL: J102.17, U2.SDA
NRST: J103.16
unnamed: Power_Head1.1, U4.1 (IN)
PA0: J103.15, U1.3 (1Y)
PA1: J103.14, U1.5 (2Y)
PA6: J103.9, U1.11 (3Y)
PA7: J103.8, U1.13 (4Y)
PB6: J102.14, U3.3 (1Y)
PB7: J102.15, U3.5 (2Y)
USART_RX: J103.12, USART_Conn1.1
USART_TX: J103.13, USART_Conn1.2
VB: J103.20

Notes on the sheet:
Differntial ICS for ENCODERS
USART Communication
Motor Connector PINS
Motor ENCODER PINS

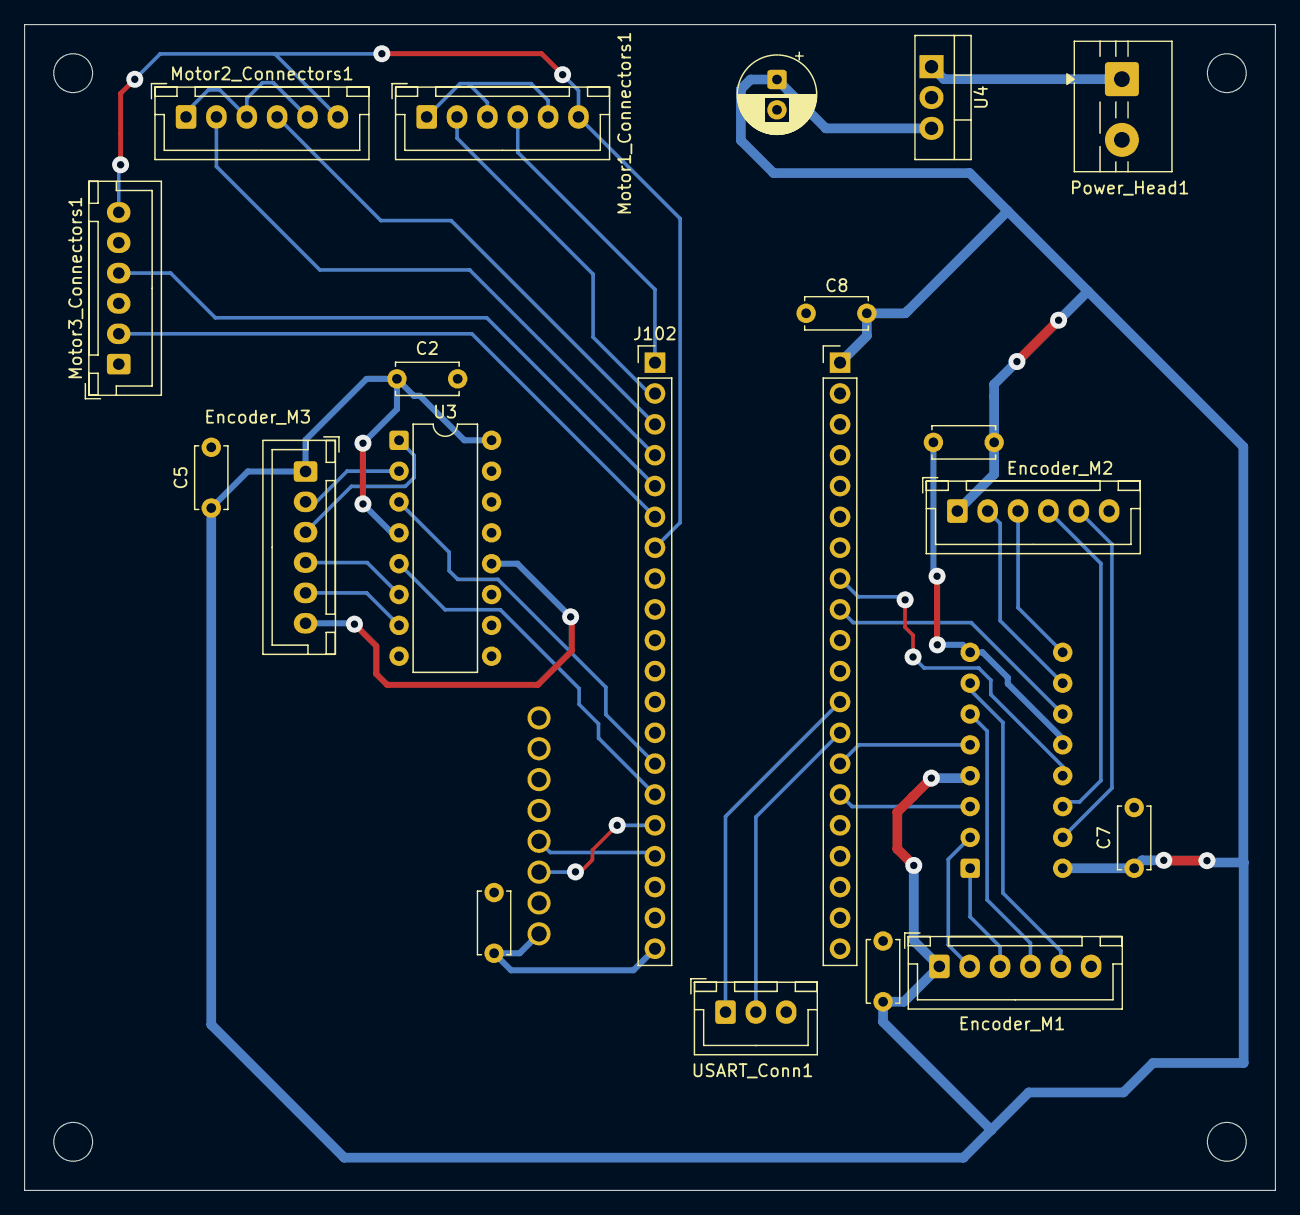
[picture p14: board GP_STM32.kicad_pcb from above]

Board: 2 copper layers, 103.0 x 96.0 mm, 22 parts (1 on the bottom side), 33 nets.

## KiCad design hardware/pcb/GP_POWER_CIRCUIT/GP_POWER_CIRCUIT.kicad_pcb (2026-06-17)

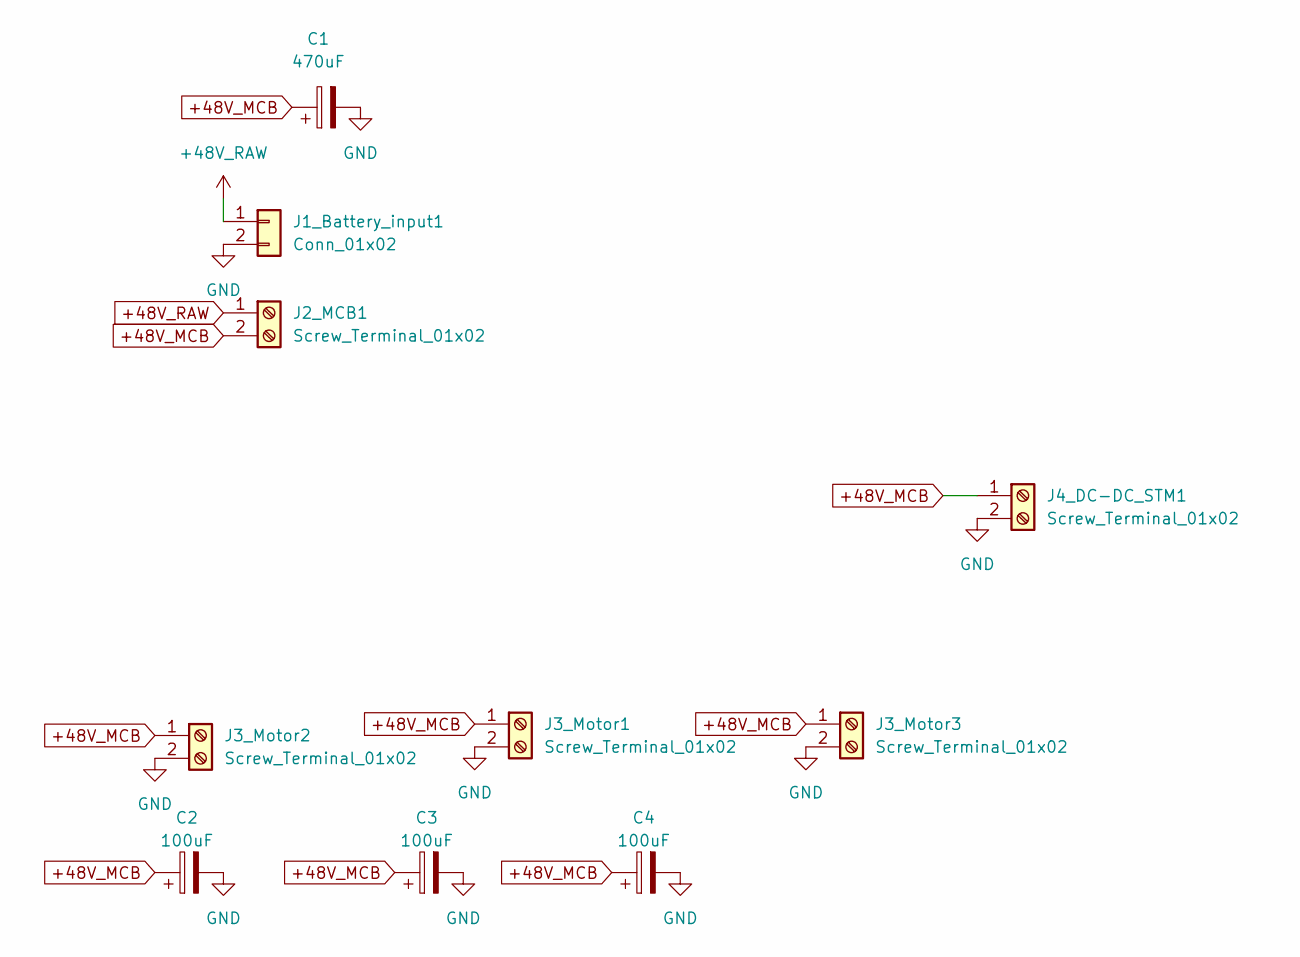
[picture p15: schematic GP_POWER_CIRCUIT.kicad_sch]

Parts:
C1: 470uF; CP_Radial_D10.0mm_P5.00mm
C2, C3, C4: 100uF; C_Disc_D5.0mm_W2.5mm_P2.50mm
J1_Battery_input1: Conn_01x02; AMASS_XT60-M_1x02_P7.20mm_Vertical
J2_MCB1, J3_Motor1, J3_Motor2, J3_Motor3, J4_DC-DC_STM1: Screw_Terminal_01x02; TerminalBlock_Phoenix_MKDS-1,5-2_1x02_P5.00mm_Horizontal

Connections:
+48V_MCB: C1.1, C2.1, C3.1, C4.1, J2_MCB1.2, J3_Motor1.1, J3_Motor2.1, J3_Motor3.1, J4_DC-DC_STM1.1
+48V_RAW: J1_Battery_input1.1, J2_MCB1.1
GND: C1.2, C2.2, C3.2, C4.2, J1_Battery_input1.2, J3_Motor1.2, J3_Motor2.2, J3_Motor3.2, J4_DC-DC_STM1.2

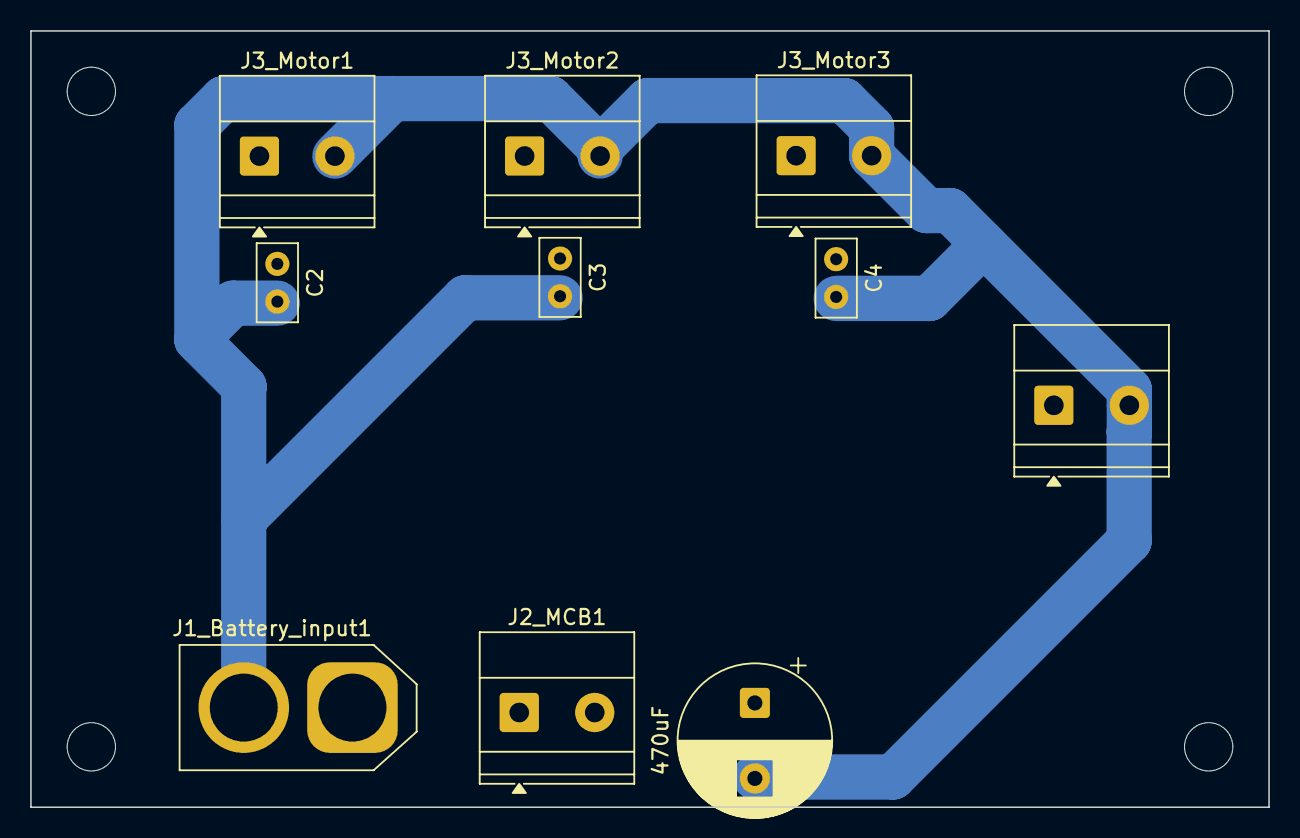
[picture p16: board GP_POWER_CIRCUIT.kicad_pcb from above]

Board: 2 copper layers, 82.0 x 51.4 mm, 10 parts (0 on the bottom side), 3 nets.

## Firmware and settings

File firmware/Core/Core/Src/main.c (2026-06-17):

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
/* Includes ------------------------------------------------------------------*/
#include "main.h"
#include "cmsis_os.h"
#include "usb_device.h"

/* USER CODE BEGIN Includes */
#include <string.h>// <-- ADDED: For serial messages
#include <stdio.h>
#include "mpu6050.h"
#include "FreeRTOS.h"
#include "task.h"
#include "usbd_cdc_if.h"
#include "Ekf.h"
#include "lqr.h"



//#include "Robot.h"



/* USER CODE END Includes */

I2C_HandleTypeDef hi2c1;

IWDG_HandleTypeDef hiwdg;

TIM_HandleTypeDef htim2;
TIM_HandleTypeDef htim3;
TIM_HandleTypeDef htim4;
TIM_HandleTypeDef htim11;

UART_HandleTypeDef huart2;
DMA_HandleTypeDef hdma_usart2_rx;
DMA_HandleTypeDef hdma_usart2_tx;

osThreadId VelocityTaskHandle;
osThreadId BalanceTaskHandle;
/* USER CODE BEGIN PV */

// Macros
//#define TIMER_FREQ_HZ   80000   // was 40000
//#define MAX_SPEED_HZ    28000
#define MAX_SPEED_HZ    28000   // was 28000
#define TIMER_FREQ_HZ 70021

#define BALANCE_TASK_LOOP_MS 5
#define VELOCITY_TASK_LOOP_MS 20 // 50 Hz
#define USTEP_8              8
#define USTEP_16             16

// Constants for controlling the stepper motors
#define STEPS_PER_REV     3200        // 200 steps × 16 microsteps — match your DM556T DIP switches
#define STEPS_PER_RAD     (STEPS_PER_REV / (2.0f * 3.14159f))  // ~509.3 steps/rad
#define TORQUE_TO_OMEGA   1.5f    /* (rad/s) / Nm — tune this */
#define ENA_DEADBAND_HZ  150   // tune this — below this speed, disable motor
//#define TORQUE_TO_OMEGA   0.5f    /* (rad/s) / Nm — tune this */
//#define TORQUE_TO_OMEGA   1.0f
//#define TORQUE_TO_OMEGA   1.5f
//#define TORQUE_TO_OMEGA   4.0f
//#define TORQUE_TO_OMEGA   2.5f
//#define TORQUE_TO_OMEGA   3.0f
//#define TORQUE_TO_OMEGA   4.0f
//#define TORQUE_TO_OMEGA   5.0f

#define ENCODER_CPR  4000.0f


// ═══════════════════════════════════════════════════════════
// PHYSICAL GEOMETRY PARAMETERS
// ═══════════════════════════════════════════════════════════
#define BALL_DIAMETER_MM    350.0f
#define WHEEL_DIAMETER_MM   125.0f
#define RK                  (BALL_DIAMETER_MM  / 2000.0f)  // = 0.175  m
#define RW                  (WHEEL_DIAMETER_MM / 2000.0f)  // = 0.0625 m
#define RW_OVER_RK          (RW / RK)                      // = 0.35714

#define ZENITH_ANGLE_DEG    45.0f
#define ALPHA_RAD           (ZENITH_ANGLE_DEG * 3.14159265f / 180.0f)  // = 0.7854 rad

#define GAMMA1_DEG          120.0f
#define GAMMA2_DEG          240.0f
#define GAMMA3_DEG          0.0f
#define GAMMA1_RAD          (GAMMA1_DEG * 3.14159265f / 180.0f)
#define GAMMA2_RAD          (GAMMA2_DEG * 3.14159265f / 180.0f)
#define GAMMA3_RAD          (GAMMA3_DEG * 3.14159265f / 180.0f)

// ═══════════════════════════════════════════════════════════
// KINEMATIC MIXING COEFFICIENTS
// Forward kinematics: ball velocity from wheel angular velocity
//
// vx = (Rw/Rk) × [−sin(γ1)·ω1 − sin(γ2)·ω2 − sin(γ3)·ω3]
// vy = (Rw/Rk) × [+cos(γ1)·ω1 + cos(γ2)·ω2 + cos(γ3)·ω3]
//
// Substituting γ1=120°, γ2=240°, γ3=0°, Rw/Rk=0.35714:
//   sin120°=+0.8660, sin240°=−0.8660, sin0°= 0.0000
//   cos120°=−0.5000, cos240°=−0.5000, cos0°=+1.0000
// ═══════════════════════════════════════════════════════════
#define KIN_VX_W1   (-(RW_OVER_RK) * sinf(GAMMA1_RAD))  // = −0.3093
#define KIN_VX_W2   (-(RW_OVER_RK) * sinf(GAMMA2_RAD))  // = +0.3093
#define KIN_VX_W3   (-(RW_OVER_RK) * sinf(GAMMA3_RAD))  // =  0.0000

#define KIN_VY_W1   (+(RW_OVER_RK) * cosf(GAMMA1_RAD))  // = −0.1786
#define KIN_VY_W2   (+(RW_OVER_RK) * cosf(GAMMA2_RAD))  // = −0.1786
#define KIN_VY_W3   (+(RW_OVER_RK) * cosf(GAMMA3_RAD))  // = +0.3571

#define TILT_LIMIT_RAD    0.1f


#define STEPS_PER_RAD_8     254.648f
#define STEPS_PER_RAD_16    509.296f
#define USTEP_THRESH_HIGH   1.5f
#define USTEP_THRESH_LOW    0.8f
#define USTEP_CONFIRM_TICKS 5

#define J_WHEEL             0.00320//0.0006f       // kg·m² — tune to your wheel's inertia if robot vibrates could use this  0.00320

#define TILT_HARD_STOP_RAD 0.35f   // ~20° recovery ceiling
#define PHI_OFFSET    -0.022f
#define THETA_OFFSET  -0.185f


// USART
#define UART_RX_BUF_SIZE  64
#define CMD_PACKET_SIZE   15
static uint8_t uart_rx_buf[UART_RX_BUF_SIZE];
static uint8_t uart_tx_buf[192];
volatile uint8_t robot_mode = 0; // 0 = Standby/Disabled, 1 = Active Balancing
uint8_t prev_robot_mode = 0;

extern float integral_error_x;
extern float integral_error_y;



volatile int32_t m1_speed_hz = 0;
volatile int32_t m2_speed_hz = 0;
volatile int32_t m3_speed_hz = 0;

// Accumulators for the Bresenham stepping algorithm
volatile uint32_t m1_accumulator = 0;
volatile uint32_t m2_accumulator = 0;
volatile uint32_t m3_accumulator = 0;

// Encoder Tracking Variables
volatile int32_t enc1_velocity = 0; // Ticks per loop for Wheel 1
volatile int32_t enc2_velocity = 0; // Ticks per loop for Wheel 2
volatile int32_t enc3_velocity = 0; // Ticks per loop for Wheel 3

// Previous timer counts
uint32_t enc1_prev = 0;
uint16_t enc2_prev = 0;
uint16_t enc3_prev = 0;

//static float m1_omega = 0.0f;
//static float m2_omega = 0.0f;
//static float m3_omega = 0.0f;

MPU6050_t MPU6050;


/* USER CODE END PV */

void SystemClock_Config(void);
static void MX_GPIO_Init(void);
static void MX_DMA_Init(void);
static void MX_I2C1_Init(void);
static void MX_TIM2_Init(void);
static void MX_TIM4_Init(void);
static void MX_USART2_UART_Init(void);
static void MX_TIM3_Init(void);
static void MX_TIM11_Init(void);
static void MX_IWDG_Init(void);
void Velocit_Task(void const * argument);
void Balance_Task(void const * argument);

/* USER CODE BEGIN PFP */

void Update_Encoder_Velocities(void);
void Set_Motor_Speeds(int32_t speed1, int32_t speed2, int32_t speed3);
void convert_torque_to_speed(float t1, float t2, float t3);
void USART2_IRQHandler_Extension(void);




/* USER CODE END PFP */

/**
  * @brief  The application entry point.
  * @retval int
  */
int main(void)
{

  /* MCU Configuration--------------------------------------------------------*/

  /* Reset of all peripherals, Initializes the Flash interface and the Systick. */
  HAL_Init();

  /* Configure the system clock */
  SystemClock_Config();

  /* Initialize all configured peripherals */
  MX_GPIO_Init();
  MX_DMA_Init();
  MX_I2C1_Init();
  MX_TIM2_Init();
  MX_TIM4_Init();
  MX_USART2_UART_Init();
  MX_TIM3_Init();
  MX_TIM11_Init();
//  MX_IWDG_Init();
  /* USER CODE BEGIN 2 */
  /* USER CODE BEGIN 2 */
  HAL_TIM_Base_Start_IT(&htim11);
  HAL_TIM_Encoder_Start(&htim2, TIM_CHANNEL_ALL);
  HAL_TIM_Encoder_Start(&htim3, TIM_CHANNEL_ALL);
  HAL_TIM_Encoder_Start(&htim4, TIM_CHANNEL_ALL);
  MX_USB_DEVICE_Init();
  HAL_UART_Receive_DMA(&huart2, uart_rx_buf, UART_RX_BUF_SIZE);
  __HAL_UART_ENABLE_IT(&huart2, UART_IT_IDLE);



  CoreDebug->DEMCR |= CoreDebug_DEMCR_TRCENA_Msk;
  DWT->CYCCNT = 0;
  DWT->CTRL  |= DWT_CTRL_CYCCNTENA_Msk;

   // 1. Wait a moment for the MPU6050 to power up
 HAL_Delay(100);
 HAL_StatusTypeDef mpu_status = HAL_I2C_IsDeviceReady(&hi2c1, (0x68 << 1), 3, 100);
// if (MPU6050_Init(&hi2c1) != 0 && mpu_status != HAL_OK) {
////     // Initialization failed. Blink fast and stop.
////     sprintf(usb_buf, sizeof(usb_buf), "MPU6050 INIT FAILED! Check wiring.\r\n");
////     CDC_Transmit_FS((uint8_t*)usb_buf, strlen(usb_buf));
//     while (1) {
//         HAL_GPIO_TogglePin(Black_Pill_LED_GPIO_Port, Black_Pill_LED_Pin);
//         HAL_Delay(50);
//     }
// }

  /* USER CODE END 2 */

  /* USER CODE BEGIN RTOS_MUTEX */
  /* add mutexes, ... */
  /* USER CODE END RTOS_MUTEX */

  /* USER CODE BEGIN RTOS_SEMAPHORES */
  /* add semaphores, ... */
  /* USER CODE END RTOS_SEMAPHORES */

  /* USER CODE BEGIN RTOS_TIMERS */
  /* start timers, add new ones, ... */
  /* USER CODE END RTOS_TIMERS */

  /* USER CODE BEGIN RTOS_QUEUES */
  /* add queues, ... */
  /* USER CODE END RTOS_QUEUES */

  /* Create the thread(s) */
  /* definition and creation of VelocityTask */
  osThreadDef(VelocityTask, Velocit_Task, osPriorityNormal, 0, 512);
  VelocityTaskHandle = osThreadCreate(osThread(VelocityTask), NULL);

  /* definition and creation of BalanceTask */
  osThreadDef(BalanceTask, Balance_Task, osPriorityHigh, 0, 2048);
  BalanceTaskHandle = osThreadCreate(osThread(BalanceTask), NULL);

  /* USER CODE BEGIN RTOS_THREADS */
  /* add threads, ... */
  /* USER CODE END RTOS_THREADS */

  /* Start scheduler */
  osKernelStart();

  /* We should never get here as control is now taken by the scheduler */

  /* Infinite loop */
  /* USER CODE BEGIN WHILE */
  while (1)
  {
    /* USER CODE END WHILE */

    /* USER CODE BEGIN 3 */
  }
  /* USER CODE END 3 */
}

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
/* USER CODE BEGIN 4 */
// ═══════════════════════════════════════════════════════════════
// CDC Receive — parses velocity commands from laptop
// Protocol: [0xAA][0x55][vx f32LE][vy f32LE][yaw_rate f32LE][XOR checksum]
// Total: 15 bytes
// Send from Python:
//   payload = struct.pack('<3f', vx, vy, yaw_rate)
//   checksum = 0
//   for b in payload: checksum ^= b
//   ser.write(bytes([0xAA, 0x55]) + payload + bytes([checksum]))
// ═══════════════════════════════════════════════════════════════
void CDC_ReceiveCallback(uint8_t* buf, uint32_t len)
{
    if (len < 15) return;

    // Find sync header
    for (uint32_t i = 0; i <= len - 15; i++) {
        if (buf[i] == 0xAA && buf[i+1] == 0x55) {
            // Verify checksum (XOR of bytes 2–13)
            uint8_t chk = 0;
            for (int k = 2; k < 14; k++) {
                chk ^= buf[i+k];
            }
            if (chk != buf[i+14]) continue;  // bad checksum, skip

            // Parse three floats (little-endian)
            float vx, vy, yaw_rate;
            memcpy(&vx,       &buf[i+2],  4);
            memcpy(&vy,       &buf[i+6],  4);
            memcpy(&yaw_rate, &buf[i+10], 4);

            // Update LQR references
            updateReferencesFromROS(vx, vy, yaw_rate, HAL_GetTick());
            return;
        }
    }
}

void USART2_IRQHandler_Extension(void)
{
    /* Only handle IDLE line interrupt */
    if (!__HAL_UART_GET_FLAG(&huart2, UART_FLAG_IDLE)) return;
    __HAL_UART_CLEAR_IDLEFLAG(&huart2);

    uint16_t bytes = UART_RX_BUF_SIZE - (uint16_t)__HAL_DMA_GET_COUNTER(huart2.hdmarx);

    if (bytes < 16) goto reset_dma;

    for (uint16_t i = 0; i + 16 <= bytes; i++) {
        if (uart_rx_buf[i] != 0xAA || uart_rx_buf[i+1] != 0x55) continue;

        uint8_t chk = 0;
        for (int k = 2; k < 15; k++) chk ^= uart_rx_buf[i+k];
        if (chk != uart_rx_buf[i+15]) continue;

        uint8_t rx_mode = uart_rx_buf[i+2];
        float vx, vy, yaw;
        memcpy(&vx,  &uart_rx_buf[i+3],  4);
        memcpy(&vy,  &uart_rx_buf[i+7],  4);
        memcpy(&yaw, &uart_rx_buf[i+11], 4);

        robot_mode = rx_mode;
        updateReferencesFromROS(vx, vy, yaw, HAL_GetTick());
        break;
    }

reset_dma:
    HAL_UART_DMAStop(&huart2);
    HAL_UART_Receive_DMA(&huart2, uart_rx_buf, UART_RX_BUF_SIZE);
}


void Set_Motor_Speeds(int32_t speed1, int32_t speed2, int32_t speed3) {
    m1_speed_hz = speed1;
    m2_speed_hz = speed2;
    m3_speed_hz = speed3;
}

void Update_Encoder_Velocities(void) {
    // ----------------------------------------------------
    // MOTOR 1 (TIM2 is a 32-bit timer on the F411)
    // ----------------------------------------------------
    uint32_t enc1_current = htim2.Instance->CNT;
    enc1_velocity = (int32_t)(enc1_current - enc1_prev);
    enc1_prev = enc1_current;

    // ----------------------------------------------------
    // MOTOR 2 (TIM3 is a 16-bit timer)
    // ----------------------------------------------------
    uint16_t enc2_current = htim3.Instance->CNT;
    int16_t enc2_diff  = (int16_t)(enc2_current - enc2_prev);
    enc2_velocity = (int32_t)enc2_diff;
    enc2_prev = enc2_current;

    // ----------------------------------------------------
    // MOTOR 3 (TIM4 is a 16-bit timer)
    // ----------------------------------------------------
    uint16_t enc3_current = htim4.Instance->CNT;
    int16_t enc3_diff  = (int16_t)(enc3_current - enc3_prev);
    enc3_velocity = (int32_t)enc3_diff;
    enc3_prev = enc3_current;
}

/* ═══════════════════════════════════════════════════════════════
 * convert_torque_to_speed — DIRECT mapping, no integration
 *
 * The LQR torque is treated as a velocity command proportion.
 * TORQUE_TO_OMEGA maps Nm to rad/s. Tune this constant on hardware:
 *   - Too large  → oscillation, aggressive response
 *   - Too small  → sluggish, falls over slowly
 * Start at 16.0, halve it if the robot oscillates.
 * ═══════════════════════════════════════════════════════════════ */
// Add these static variables inside convert_torque_to_speed:
void convert_torque_to_speed(float t1, float t2, float t3)
{
    // Persistence for the ramping logic (prevents wheel slip)
    static int32_t prev_spd1 = 0, prev_spd2 = 0, prev_spd3 = 0;

    // --- TUNING PARAMETERS ---

    // TORQUE_TO_OMEGA: Master sensitivity. Start at 6.0 for 17-22kg [History]

    // STEPS_PER_RAD:
    // For 3200: (3200 / 2*PI) = 509.296f
    // For 6400: (6400 / 2*PI) = 1018.592f

    // MIN_STEPS: Deadband to stop "stepper hum" and IMU pollution.
    // Recommended: 1200 Hz for 3200x; 2400 Hz for 6400x [1, 2]

    // MAX_RAMP: Acceleration limit per loop (dt=0.002s).
    // Tune this to prevent wheel slip on the ball.
    // For 3200: 320 steps/loop (160,000 steps/s^2)
    // For 6400: 640 steps/loop (320,000 steps/s^2)
    const int32_t MAX_RAMP   = 80;

    // MAX_SPEED_HZ: Hardware limit based on 60V supply corner speed.
    // For 3200: 14,000 Hz (~2.2 m/s robot speed)
    // For 6400: 28,000 Hz (~2.2 m/s robot speed) [2, 3]

    // 1. Map Torque directly to Radian Velocity (rad/s)
    float w1 = t1 * TORQUE_TO_OMEGA;
    float w2 = t2 * TORQUE_TO_OMEGA;
    float w3 = t3 * TORQUE_TO_OMEGA;

    // 2. Convert Rad/s to Target Step Frequency (Hz)
    int32_t target1 = (int32_t)(w1 * STEPS_PER_RAD);
    int32_t target2 = (int32_t)(w2 * STEPS_PER_RAD);
    int32_t target3 = (int32_t)(w3 * STEPS_PER_RAD);

    // 3. Deadband with hysteresis — prevents 1199↔1201 toggling
    //    DEAD_EXIT  = stop threshold  — if below this, motor stops
    //    DEAD_ENTER = start threshold — need this speed to START moving
    //    Effect: motor stops at 1200, but needs 1400 to restart
    //    This eliminates the clicking at small angles
//    const int32_t DEAD_EXIT  = 0;
//    const int32_t DEAD_ENTER = 0;
//
//    if (abs(target1) < DEAD_EXIT)  { target1 = 0; prev_spd1 = 0; }
//    else if (abs(target1) < DEAD_ENTER && prev_spd1 == 0) { target1 = 0; }
//
//    if (abs(target2) < DEAD_EXIT)  { target2 = 0; prev_spd2 = 0; }
//    else if (abs(target2) < DEAD_ENTER && prev_spd2 == 0) { target2 = 0; }
//
//    if (abs(target3) < DEAD_EXIT)  { target3 = 0; prev_spd3 = 0; }
//    else if (abs(target3) < DEAD_ENTER && prev_spd3 == 0) { target3 = 0; }


    // 4. Rate Limiting (Ramp): Protects the 17kg mass from sudden jerk/slip
    int32_t diff1 = target1 - prev_spd1;
    int32_t diff2 = target2 - prev_spd2;
    int32_t diff3 = target3 - prev_spd3;

    if (diff1 >  MAX_RAMP) diff1 =  MAX_RAMP;
    if (diff1 < -MAX_RAMP) diff1 = -MAX_RAMP;
    if (diff2 >  MAX_RAMP) diff2 =  MAX_RAMP;
    if (diff2 < -MAX_RAMP) diff2 = -MAX_RAMP;
    if (diff3 >  MAX_RAMP) diff3 =  MAX_RAMP;
    if (diff3 < -MAX_RAMP) diff3 = -MAX_RAMP;

    // 5. Update Persistent Speeds
    prev_spd1 += diff1;
    prev_spd2 += diff2;
    prev_spd3 += diff3;

    // 6. Final Hardware Output (Clamped to Electrical Corner Speed)
    Set_Motor_Speeds(
        (int32_t)fmaxf(-MAX_SPEED_HZ, fminf(MAX_SPEED_HZ, (float)prev_spd1)),
        (int32_t)fmaxf(-MAX_SPEED_HZ, fminf(MAX_SPEED_HZ, (float)prev_spd2)),
        (int32_t)fmaxf(-MAX_SPEED_HZ, fminf(MAX_SPEED_HZ, (float)prev_spd3))
    );
}
/* USER CODE END 4 */

/* USER CODE BEGIN Header_Velocit_Task */
/**
  * @brief  Function implementing the VelocityTask thread.
  * @param  argument: Not used
  * @retval None
  */
/* USER CODE END Header_Velocit_Task */
void Velocit_Task(void const * argument)
{
  /* init code for USB_DEVICE */
//  MX_USB_DEVICE_Init();
  /* USER CODE BEGIN 5 */
	TickType_t xLastWakeTime = xTaskGetTickCount();

  /* Infinite loop */
  for(;;)
  {
	  vTaskDelayUntil(&xLastWakeTime, 10);
  }
  /* USER CODE END 5 */
}

/* USER CODE BEGIN Header_Balance_Task */
/**
* @brief Function implementing the BalanceTask thread.
* @param argument: Not used
* @retval None
*/
/* USER CODE END Header_Balance_Task */
void Balance_Task(void const * argument)
{
  /* USER CODE BEGIN Balance_Task */
    const float      DT_S       = 0.005f;
    const TickType_t EKF_PERIOD = pdMS_TO_TICKS(5);
    static char      usb_buf[256];
    uint32_t         tick_count = 0;
    const float      D2R        = 3.14159265f / 180.0f;
    static float gyroz_filter = 0.0f;
    const float gyroz_LPF = 0.05f;


   // static const float TICKS_TO_RADS = 0.785398f;
   //static const float TICKS_TO_RADS = 0.392699f; // (x16)    2pi/(microstepping * delta t)
   //static const float TICKS_TO_RADS = 3.1415926f; // (x2)    2pi/(microstepping * delta t)
//   static const float TICKS_TO_RADS = (2.0f * 3.14159265f) / (STEPS_PER_REV * DT_S);
    static const float TICKS_TO_RADS = (2.0f * 3.14159265f) / (ENCODER_CPR * DT_S);


    vTaskDelay(pdMS_TO_TICKS(200));
    MPU6050_Init(&hi2c1);
    vTaskDelay(pdMS_TO_TICKS(50));
    BallbotEKF_Init();

    // ── Gyro bias calibration ───────────────────────────────────
    // FIX: disable motors so vibration does not corrupt bias
    HAL_GPIO_WritePin(ENABLE_PIN_GPIO_Port, ENABLE_PIN_Pin, GPIO_PIN_SET);
    vTaskDelay(pdMS_TO_TICKS(2000));

    float gyro_bias_x = 0.0f, gyro_bias_y = 0.0f, gyro_bias_z = 0.0f;
    const int CAL_SAMPLES = 400;
    for (int i = 0; i < CAL_SAMPLES; i++) {
        MPU6050_Read_All(&hi2c1, &MPU6050);
        gyro_bias_x += MPU6050.Gx;
        gyro_bias_y += MPU6050.Gy;
        gyro_bias_z += MPU6050.Gz;
        vTaskDelay(pdMS_TO_TICKS(5));   // FIX: was HAL_Delay — yields FreeRTOS
    }
    gyro_bias_x /= CAL_SAMPLES;
    gyro_bias_y /= CAL_SAMPLES;
    gyro_bias_z /= CAL_SAMPLES;

    // Re-enable motors after calibration
    HAL_GPIO_WritePin(ENABLE_PIN_GPIO_Port, ENABLE_PIN_Pin, GPIO_PIN_RESET);

    BallbotStates ekf = {0};
    TickType_t xLastWake = xTaskGetTickCount();

  /* Infinite loop */
  for(;;)
  {
      tick_count++;
            if (robot_mode == 0) {
                Set_Motor_Speeds(0, 0, 0);
                HAL_GPIO_WritePin(ENABLE_PIN_GPIO_Port, ENABLE_PIN_Pin, GPIO_PIN_SET); // Keep drivers offline

                BallbotEKF_Init();
                ekf = (BallbotStates){0};
                integral_error_x = 0.0f;
                integral_error_y = 0.0f;

                if (prev_robot_mode != robot_mode) {
                    CDC_Transmit_FS((uint8_t*)"MOTORS_DISABLED\r\n", 17);
                    if (huart2.gState == HAL_UART_STATE_READY)
                        HAL_UART_Transmit_DMA(&huart2, (uint8_t*)"MOTORS_DISABLED\r\n", 17);
                    prev_robot_mode = robot_mode;
                }

                vTaskDelayUntil(&xLastWake, EKF_PERIOD);
                continue;
            }

            if (prev_robot_mode != robot_mode) {
                HAL_GPIO_WritePin(ENABLE_PIN_GPIO_Port, ENABLE_PIN_Pin, GPIO_PIN_RESET); // Energize drivers
                xLastWake = xTaskGetTickCount();
                CDC_Transmit_FS((uint8_t*)"MOTORS_ENABLED\r\n", 16);
                if (huart2.gState == HAL_UART_STATE_READY)
                    HAL_UART_Transmit_DMA(&huart2, (uint8_t*)"MOTORS_ENABLED\r\n", 16);
                prev_robot_mode = robot_mode;
            }

       Update_Encoder_Velocities();
       MPU6050_Read_All(&hi2c1, &MPU6050);

       float gyro_x  = (MPU6050.Gx - gyro_bias_x) * D2R;
       float gyro_y  = (MPU6050.Gy - gyro_bias_y) * D2R;
       float gyro_z  = (MPU6050.Gz - gyro_bias_z) * D2R;
       float accel_x = MPU6050.Ax * 9.81f;
       float accel_y = MPU6050.Ay * 9.81f;
       float accel_z = MPU6050.Az * 9.81f;

       // ── Accel spike rejection ────────────────────────────────
       // FIX: use squared comparison — eliminates sqrtf() every loop
       // At rest: ax²+ay²+az² ≈ 9.81² = 96.2
       // Reject if outside [0.2g, 15g] → [2², 147²] = [4, 21609]
       float accel_mag2 = accel_x*accel_x + accel_y*accel_y + accel_z*accel_z;
       float safe_ax, safe_ay;
       if (accel_mag2 > (147.0f*147.0f) || accel_mag2 < (2.0f*2.0f)) {
           safe_ax =  9.81f * sinf(ekf.theta);
           safe_ay = -9.81f * sinf(ekf.phi) * cosf(ekf.theta);
       } else {
           safe_ax = accel_x;
           safe_ay = accel_y;
       }



       // CORRECT — replace the entire commented block with this
       float w1 = (float)enc1_velocity * TICKS_TO_RADS;
       float w2 = (float)enc2_velocity * TICKS_TO_RADS;
       float w3 = (float)enc3_velocity * TICKS_TO_RADS;

//       float enc_vx = (-0.3093f*w1) + (0.3093f*w2) + (0.0000f*w3);
//       float enc_vy = (-0.1786f*w1) + (-0.1786f*w2) + (0.3571f*w3);
//
       //BallbotEKF_Update(gyro_x, gyro_y, safe_ax, safe_ay,
                //               0, 0, DT_S, &ekf);



       // Forward kinematics: wheel angular velocity (rad/s) → ball linear velocity (m/s)
       float enc_vx = KIN_VX_W1*w1 + KIN_VX_W2*w2 + KIN_VX_W3*w3;
       float enc_vy = KIN_VY_W1*w1 + KIN_VY_W2*w2 + KIN_VY_W3*w3;
       BallbotEKF_Update(gyro_x, gyro_y, safe_ax, safe_ay,
                                 enc_vx, enc_vy, DT_S, &ekf);
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

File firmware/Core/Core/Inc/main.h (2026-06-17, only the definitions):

#define Black_Pill_LED_Pin GPIO_PIN_13
#define Black_Pill_LED_GPIO_Port GPIOC
#define ENAPLE_M3_Pin GPIO_PIN_14
#define ENAPLE_M3_GPIO_Port GPIOC
#define ENAPLE_M2_Pin GPIO_PIN_1
#define ENAPLE_M2_GPIO_Port GPIOB
#define M1_STEP_Pin GPIO_PIN_12
#define M1_STEP_GPIO_Port GPIOB
#define M1_DIR_Pin GPIO_PIN_13
#define M1_DIR_GPIO_Port GPIOB
#define M2_STEP_Pin GPIO_PIN_14
#define M2_STEP_GPIO_Port GPIOB
#define M2_DIR_Pin GPIO_PIN_15
#define M2_DIR_GPIO_Port GPIOB
#define M3_STEP_Pin GPIO_PIN_8
#define M3_STEP_GPIO_Port GPIOA
#define M3_DIR_Pin GPIO_PIN_9
#define M3_DIR_GPIO_Port GPIOA
#define ENABLE_PIN_Pin GPIO_PIN_10
#define ENABLE_PIN_GPIO_Port GPIOA
#define M3_DIR1_Pin GPIO_PIN_15
#define M3_DIR1_GPIO_Port GPIOA

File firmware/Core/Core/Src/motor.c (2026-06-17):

//#include "motor.h"
//#include <stdlib.h>
//
//// Bring in the timer handle from main.c
////extern TIM_HandleTypeDef htim1;
//
//// Define the 3 global motor objects
//Motor_t motor1;
//Motor_t motor2;
//Motor_t motor3;
//
//// Internal helper function (not in .h file)
//static void Motor_SetDirection(Motor_t* motor, int32_t speed);
//
//void Motor_Init(void) {
//    // --- Motor 1 Configuration ---
//    motor1.htim = &htim1;
//    motor1.channel = TIM_CHANNEL_1;
//    motor1.port_in1 = GPIOB;
//    motor1.pin_in1 = GPIO_PIN_13;
//    motor1.port_in2 = GPIOB;
//    motor1.pin_in2 = GPIO_PIN_14;
//
//    // --- Motor 2 Configuration ---
//    motor2.htim = &htim1;
//    motor2.channel = TIM_CHANNEL_2;
//    motor2.port_in1 = GPIOB;
//    motor2.pin_in1 = GPIO_PIN_1;
//    motor2.port_in2 = GPIOB;
//    motor2.pin_in2 = GPIO_PIN_2;
//
//    // --- Motor 3 Configuration ---
//    motor3.htim = &htim1;
//    motor3.channel = TIM_CHANNEL_3;
//    motor3.port_in1 = GPIOA;
//    motor3.pin_in1 = GPIO_PIN_6;
//    motor3.port_in2 = GPIOA;
//    motor3.pin_in2 = GPIO_PIN_7;
//
//    // Start all PWM channels
//    HAL_TIM_PWM_Start(motor1.htim, motor1.channel);
//    HAL_TIM_PWM_Start(motor2.htim, motor2.channel);
//    HAL_TIM_PWM_Start(motor3.htim, motor3.channel);
//
//    Motor_StopAll();
//}
//
//void Motor_SetSpeed(Motor_t* motor, int32_t speed) {
//    // 1. Set the motor direction
//    Motor_SetDirection(motor, speed);
//
//    // 2. Set the speed (absolute value)
//    uint32_t pwm_pulse = (uint32_t)abs(speed);
//
//    // 3. Saturate the speed
//    // The PWM_MAX is 20000, but your old file used 1000.
//    // We will scale it. Your timer is 19999.
//    // We will assume a 0-1000 input range for simplicity.
////    if (pwm_pulse > 1000) {
////        pwm_pulse = 1000;
////    }
//
//    // Scale 0-1000 to 0-19999
//    // (This is faster than floating point)
//    pwm_pulse = pwm_pulse * 19999 / 1000;
//
//    // 4. Set the PWM duty cycle
//    __HAL_TIM_SET_COMPARE(motor->htim, motor->channel, pwm_pulse);
//}
//
//static void Motor_SetDirection(Motor_t* motor, int32_t speed) {
//    if (speed > 0) {
//        // Forward
//        HAL_GPIO_WritePin(motor->port_in1, motor->pin_in1, GPIO_PIN_SET);
//        HAL_GPIO_WritePin(motor->port_in2, motor->pin_in2, GPIO_PIN_RESET);
//    } else if (speed < 0) {
//        // Backward
//        HAL_GPIO_WritePin(motor->port_in1, motor->pin_in1, GPIO_PIN_RESET);
//        HAL_GPIO_WritePin(motor->port_in2, motor->pin_in2, GPIO_PIN_SET);
//    } else {
//        // Stop (Brake)
//        HAL_GPIO_WritePin(motor->port_in1, motor->pin_in1, GPIO_PIN_RESET);
//        HAL_GPIO_WritePin(motor->port_in2, motor->pin_in2, GPIO_PIN_RESET);
//    }
//}
//
//void Motor_StopAll(void) {
//    Motor_SetSpeed(&motor1, 0);
//    Motor_SetSpeed(&motor2, 0);
//    Motor_SetSpeed(&motor3, 0);
//}

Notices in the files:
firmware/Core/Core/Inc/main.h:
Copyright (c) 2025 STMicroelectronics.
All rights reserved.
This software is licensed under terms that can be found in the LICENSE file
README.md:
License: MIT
